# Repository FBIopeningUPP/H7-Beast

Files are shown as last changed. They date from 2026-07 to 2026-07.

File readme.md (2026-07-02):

# H7 Beast

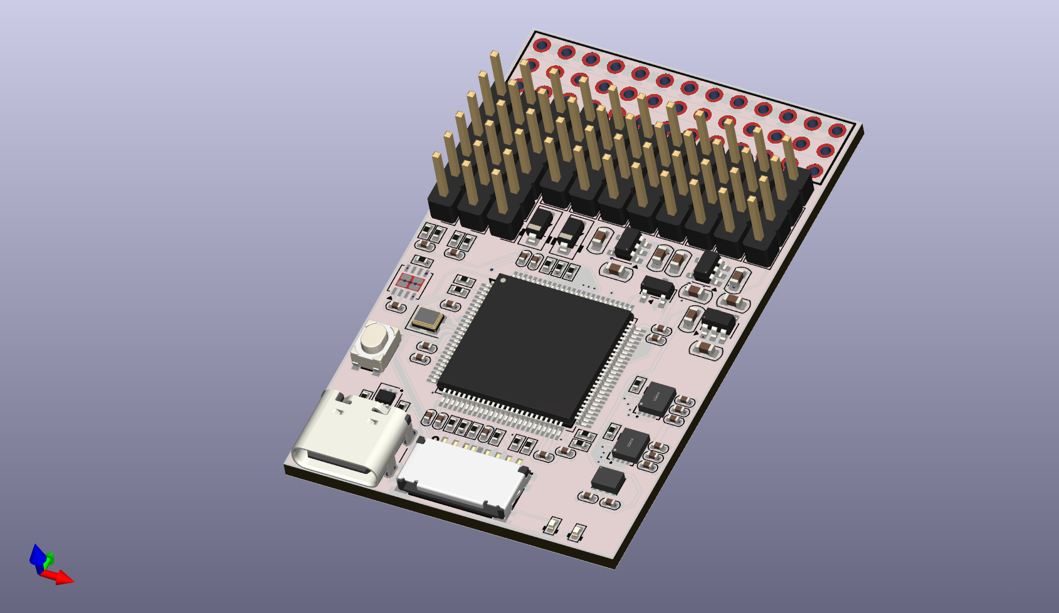
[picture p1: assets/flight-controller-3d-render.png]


H7 Beast is a small open source flight controller that is based of Betaflight, INav, ArduPilot and PX4 firmware. The size of the board with the features is amazing it's just 58x34mm wide and comes with all the features like external spi and canbus and 12 motor output with a single output for ws2812b leds

## Features

- MCU: STM32H743VIT6
- Gyroscope: 2x ICM-42688-P with low noise 3.3v Rail
- Barometer: DPS310
- Blackbox: Sd Card interface
- UARTs: 7x UARTs
- i2C: 2x i2C, 1 internal and 1 external
- SPI: 4x SPI, 3x internal 1x external
- CAN: 1x External Can
- Digital VTX Out: 1x
- MIC5219 low-noise LDO regulators

## Betaflight, INav, ArduPilot and PX4 firmware

As i have used the hardware definition by MatekH743 we can already see the target available in the configurator

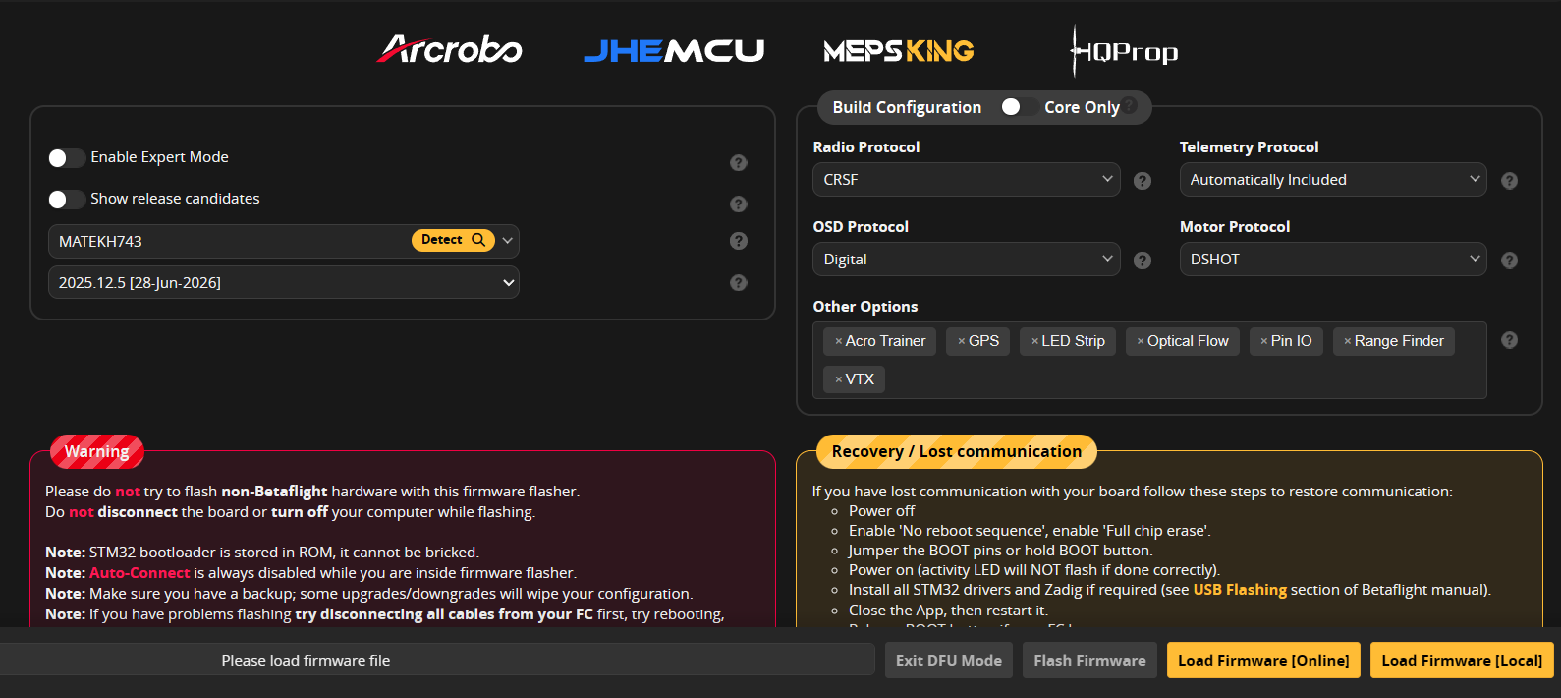
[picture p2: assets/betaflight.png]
betaflight


# PCB Design

This is my first ever 8 layer design for a compact wing based fliht controller, so it is a bit messy but functional

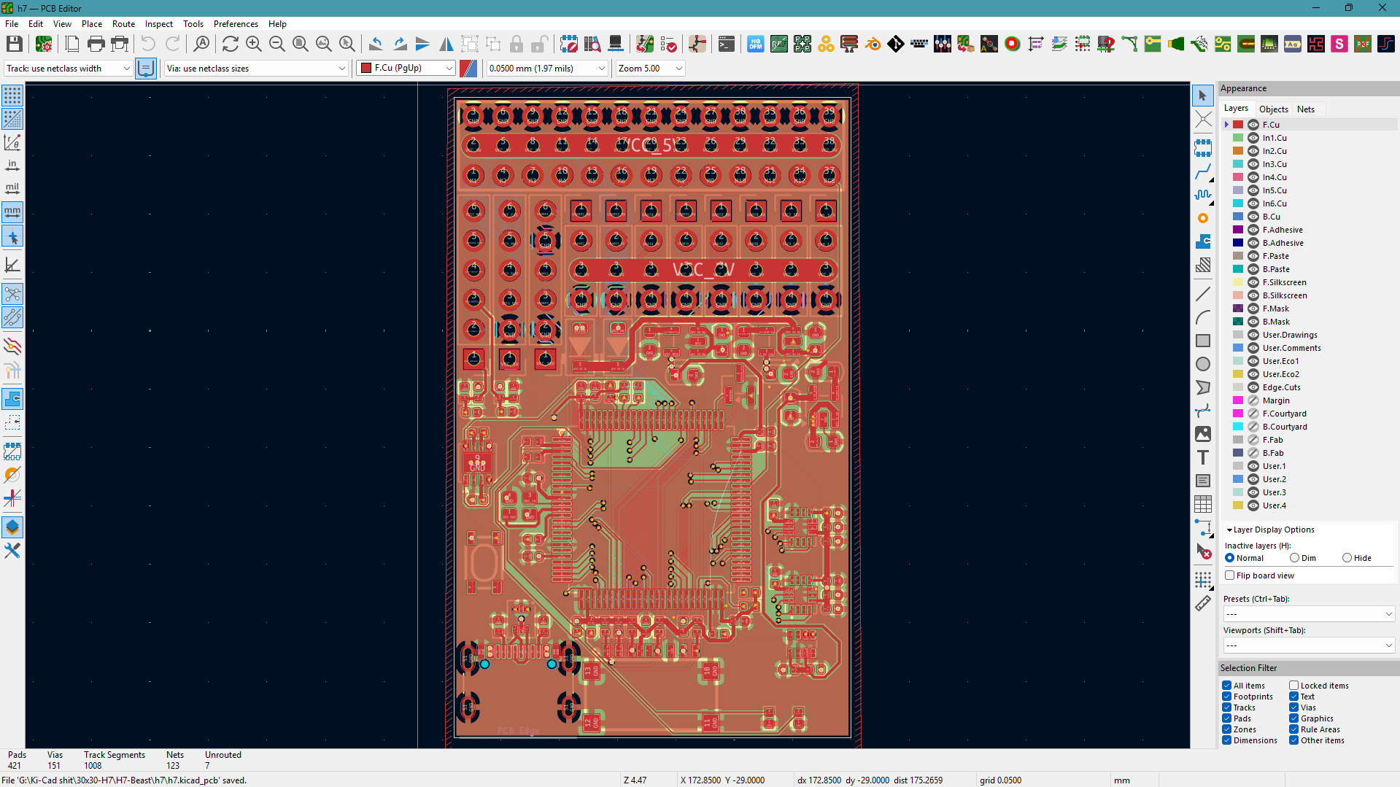
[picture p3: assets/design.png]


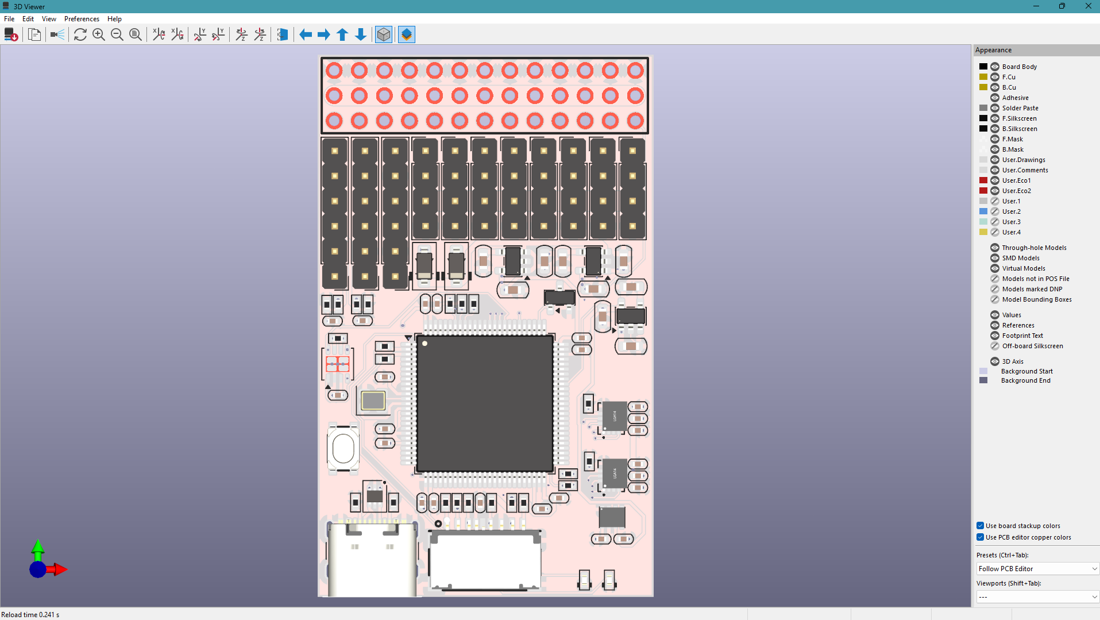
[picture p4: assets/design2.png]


With a Non-BGA chip i have the design pretty easy and managable with 8 layers, and it can fit small uavs easily, it comes with 5v circuit protection from external esc's and 5v from usb input

This can be powered through external 5v bec from the esc's or any other 5v power source

# Steps to reproduce

U can upload the [gerber](production/h7.zip) to the JLCPCB and select 1oz ENIG and 1oz copper for inner layer
For the assembly we only need the front side to be assembled so we can choose that and then upload the [bom](production/bom.csv) and [designator](production/designators.csv) files to get a quote on the bom and u can order the project

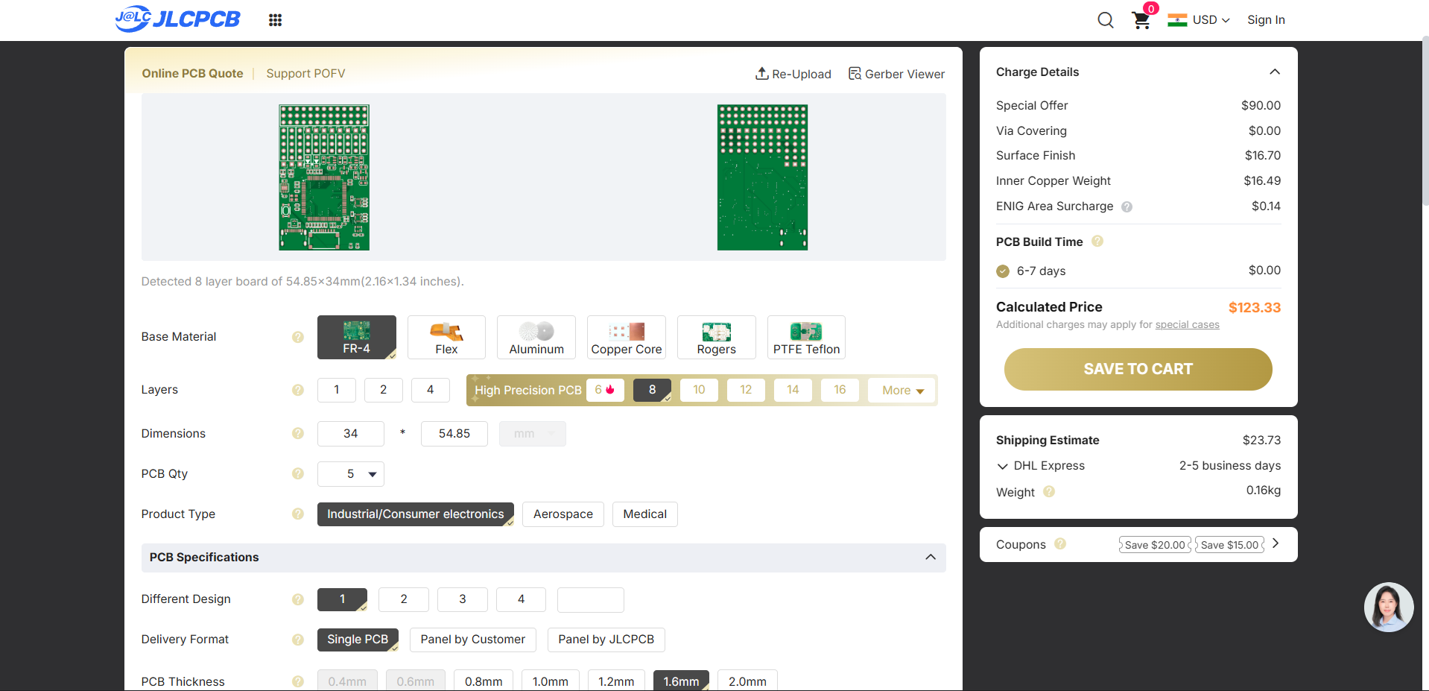
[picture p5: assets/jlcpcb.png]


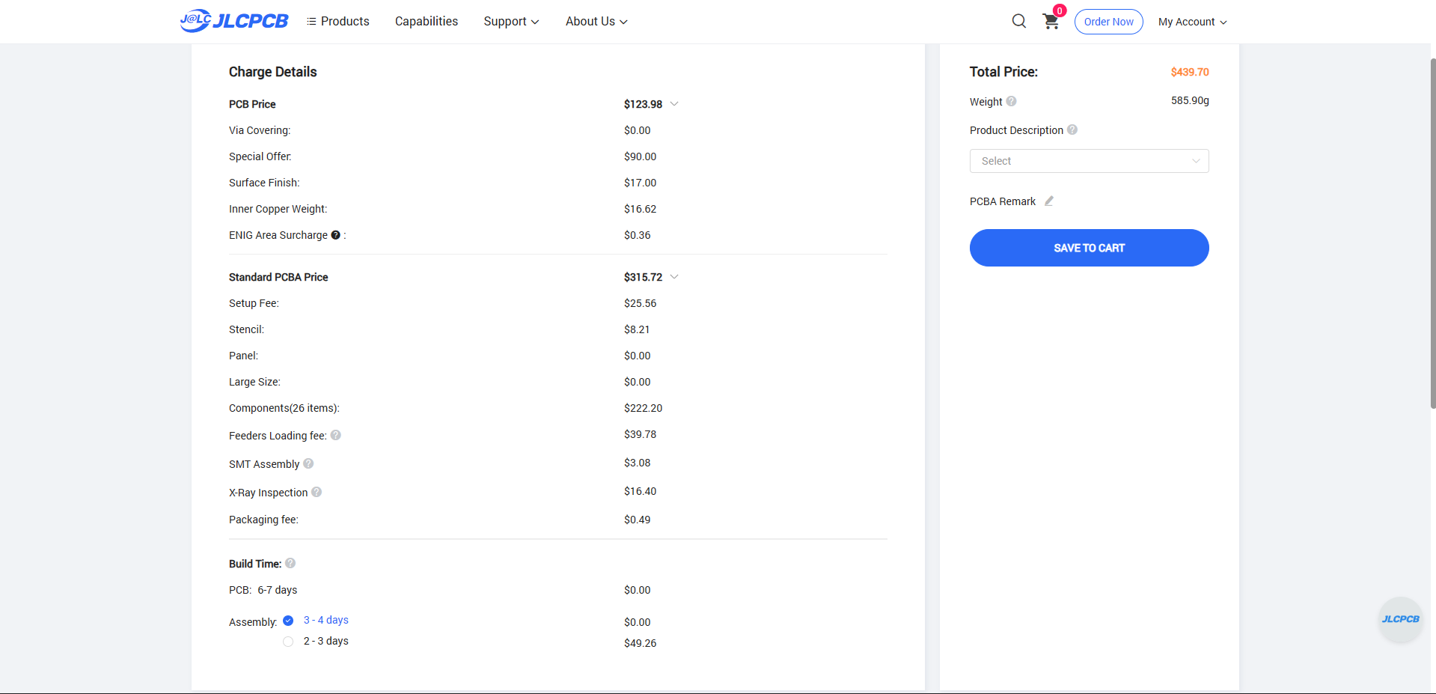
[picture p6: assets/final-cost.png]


But if u want to hand assmeble the whole thing u can also do that by using [Interactive BOM](h7/bom/ibom.html)
It lists all the components and u can select what all part u have sourced and what all parts are needed to be sourced and what u have placed and what not u have placed on the board

### USAGE OF AI

the ai was used to create [pinout](pinout.md) i copied the hwdef from ardupilot github repo and used ai to create a pinout for me so its easier for me to update things in kicad

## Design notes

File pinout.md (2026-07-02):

# H7-Beast Hardware Pinout Reference

This file is a hardware-oriented summary of the board definition in the ChibiOS
pinout format. It is meant to help with KiCad net naming, connector mapping, and
checking board-level routing.

## MCU / Board

- MCU: STM32H743xx
- Board ID: AP_HW_MATEKH743
- Crystal: 8 MHz external oscillator
- Flash size: 2048 KB
- Bootloader reserve: first 128 KB

## USB / Debug

| Function | MCU Pin | Notes |
| --- | --- | --- |
| OTG_FS_DM | PA11 | USB D- |
| OTG_FS_DP | PA12 | USB D+ |
| SWDIO | PA13 | JTAG/SWD |
| SWCLK | PA14 | JTAG/SWD |

## Motor Outputs

| Motor | MCU Pin | Timer / Channel |
| --- | --- | --- |
| M1 | PB0 | TIM8_CH2N |
| M2 | PB1 | TIM8_CH3N |
| M3 | PA0 | TIM5_CH1 |
| M4 | PA1 | TIM5_CH2 |
| M5 | PA2 | TIM5_CH3 |
| M6 | PA3 | TIM5_CH4 |
| M7 | PD12 | TIM4_CH1 |
| M8 | PD13 | TIM4_CH2 |
| M9 | PD14 | TIM4_CH3 |
| M10 | PD15 | TIM4_CH4 |
| M11 | PE5 | TIM15_CH1 |
| M12 | PE6 | TIM15_CH2 |
| M13 / WS2812 | PA8 | TIM1_CH1 |

## UART / Serial

| Port | TX | RX | Notes |
| --- | --- | --- | --- |
| USART1 | PA9 | PA10 | Telem2 |
| USART2 | PD5 | PD6 | GPS1 |
| USART3 | PD8 | PD9 | GPS2 |
| UART4 | PB9 | PB8 | Spare |
| USART6 | PC6 | PC7 | RC input / SERIAL7 |
| UART7 | PE8 | PE7 | Telem1 |
| UART8 | PE1 | PE0 | Spare |

Extra UART control pins:

- UART7 CTS: PE10
- UART7 RTS: PE9
- USART6 alternate RX option: PC7 on ALT(1)

## SPI Buses

| SPI | SCK | MISO | MOSI | Notes |
| --- | --- | --- | --- | --- |
| SPI1 | PA5 | PA6 | PD7 | IMU1 bus |
| SPI2 | PB15 | PB14 | PB13 | OSD bus |
| SPI3 | PB3 | PB4 | PB5 | External bus |
| SPI4 | PE12 | PE13 | PE14 | IMU2 / IMU3 bus |

Chip select / device pins:

- IMU1_CS: PC15
- MAX7456_CS: PB12
- IMU2_CS: PE11
- IMU3_CS: PC13
- EXT_CS1: PD4
- EXT_CS2: PE2
- EXT_CS3: PE15

## IMU / Gyro Devices

| Device | Interface | CS Pin | Notes |
| --- | --- | --- | --- |
| ICM42688 | SPI1 | PC15 | Primary IMU option |
| MPU6000 | SPI1 | PC15 | Alternate IMU option |
| ICM20602 | SPI4 | PE11 | Alternate IMU option |
| ICM42605 | SPI4 | PC13 | Backup IMU option |

## I2C Buses

| I2C | SCL | SDA |
| --- | --- | --- |
| I2C1 | PB6 | PB7 |
| I2C2 | PB10 | PB11 |

## CAN

| Function | MCU Pin | Notes |
| --- | --- | --- |
| CAN1_RX | PD0 | CAN bus RX |
| CAN1_TX | PD1 | CAN bus TX |
| CAN1_SILENT | PD3 | Silent mode control |

## Analog / ADC

| Function | MCU Pin | ADC | Notes |
| --- | --- | --- | --- |
| BATT_VOLTAGE_SENS | PC0 | ADC1 | Battery 1 voltage |
| BATT_CURRENT_SENS | PC1 | ADC1 | Battery 1 current |
| BATT2_VOLTAGE_SENS | PA4 | ADC1 | Battery 2 voltage |
| BATT2_CURRENT_SENS | PA7 | ADC1 | Battery 2 current |
| PRESSURE_SENS | PC4 | ADC1 | Airspeed / pressure |
| RSSI_ADC | PC5 | ADC1 | Analog RSSI |

Defined analog mapping values:

- HAL_BATT_MONITOR_DEFAULT: 4
- HAL_BATT_VOLT_PIN: 10
- HAL_BATT_CURR_PIN: 11
- HAL_BATT2_VOLT_PIN: 18
- HAL_BATT2_CURR_PIN: 7
- HAL_BATT_VOLT_SCALE: 11.0
- HAL_BATT_CURR_SCALE: 40.0
- HAL_BATT2_VOLT_SCALE: 11.0
- HAL_DEFAULT_AIRSPEED_PIN: 4
- BOARD_RSSI_ANA_PIN: 8

## LEDs / Beeper

| Function | MCU Pin | Notes |
| --- | --- | --- |
| LED0 | PE3 | Blue |
| LED1 | PE4 | Green |
| Beeper / ALARM | PA15 | TIM2_CH1 |

GPIO LED assignments:

- HAL_GPIO_A_LED_PIN: 91
- HAL_GPIO_B_LED_PIN: 90
- AP_NOTIFY_GPIO_LED_2_ENABLED: 1

## Storage / SD Card

| Function | MCU Pin |
| --- | --- |
| SDMMC1_D0 | PC8 |
| SDMMC1_D1 | PC9 |
| SDMMC1_D2 | PC10 |
| SDMMC1_D3 | PC11 |
| SDMMC1_CK | PC12 |
| SDMMC1_CMD | PD2 |

Flash storage settings:

- HAL_STORAGE_SIZE: 32768
- STORAGE_FLASH_PAGE: 14

## GPIO / User IO

| Function | MCU Pin | Notes |
| --- | --- | --- |
| PINIO1 | PD10 | Output, LOW default |
| PINIO2 | PD11 | Output, LOW default |

## External / Expansion Notes

- External compass probing is enabled; no built-in compass is defined.
- SPI3 is intended for external peripherals such as PixartFlow on EXT_CS1.
- DMA is configured with `DMA_PRIORITY S*` and `DMA_NOSHARE SPI1* SPI4*` in the board definition.

## Useful KiCad Net Names

When naming connectors or footprints in KiCad, these are the most useful nets to keep aligned with the board definition:

- USB: PA11, PA12
- SWD: PA13, PA14
- IMU1 SPI: PA5, PA6, PD7, PC15
- IMU2 / IMU3 SPI: PE12, PE13, PE14, PE11, PC13
- OSD SPI: PB15, PB14, PB13, PB12
- External SPI3: PB3, PB4, PB5, PD4, PE2, PE15
- UARTs: PA9/PA10, PD5/PD6, PD8/PD9, PB9/PB8, PC6/PC7, PE8/PE7, PE1/PE0
- I2C: PB6/PB7, PB10/PB11
- CAN: PD0/PD1/PD3
- ADC: PC0, PC1, PA4, PA7, PC4, PC5

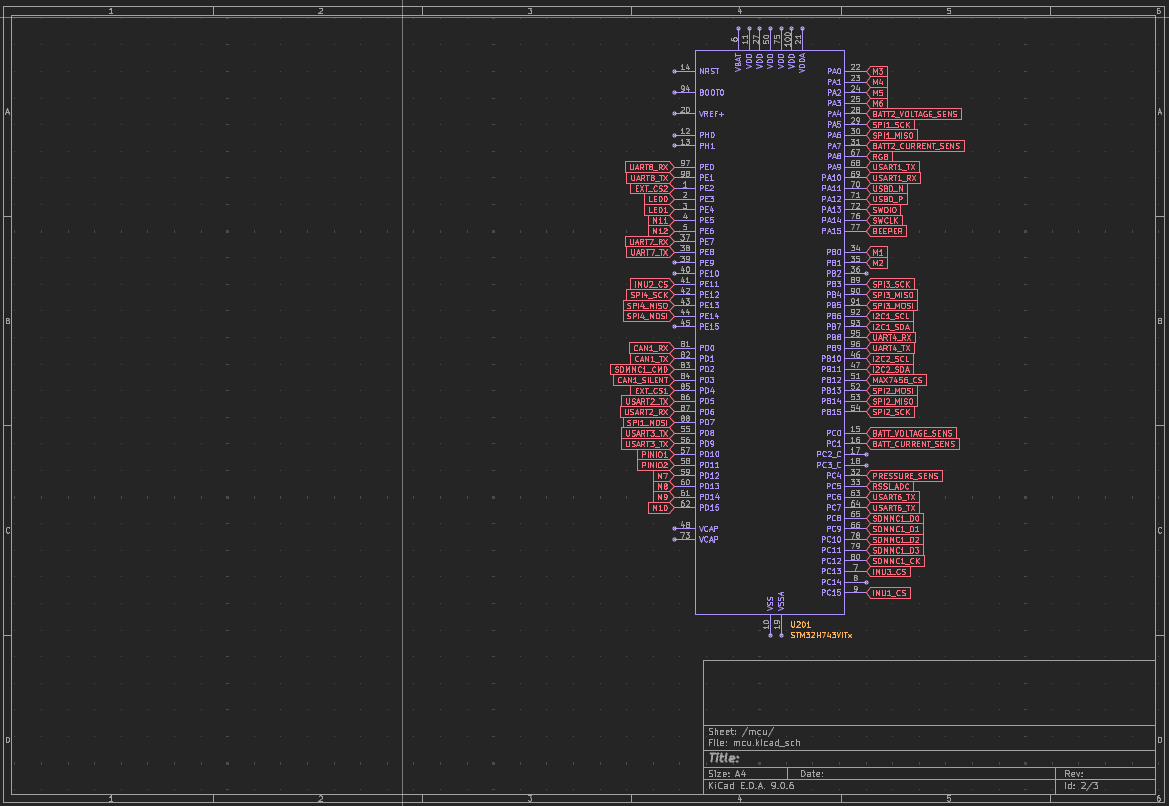
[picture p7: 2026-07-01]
images/image.png

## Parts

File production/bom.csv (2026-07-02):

Designator | Footprint | Quantity | Value | LCSC Part #
C201, C202, C203, C204, C205, C207, C210, C307, C308, C401, C402, C501, C503 | 0402 | 13 | 100nF
C206, C502 | 0402 | 2 | 1uF
C208, C209 | 0402 | 2 | 4.7uF
C301, C306 | 0402 | 2 | 10nF
C302, C304 | 0402 | 2 | 0.1uF
C303, C305 | 0402 | 2 | 2.2uF
C403, C404, C405 | 0603 | 3 | 2.2uF
C406, C407, C408 | 0603 | 3 | 470pF
C409, C410, C411 | 0603 | 3 | 100nF
D402, D403 | D_SOD-123 | 2 | B140HW-7
D501 | SOT-666 | 1 | USBLC6-2P6
J301 | PinHeader_1x06_P2.54mm_Vertical | 1 | VTX&UART1
J501 | USB_C_Receptacle_GCT_USB4105-xx-A_16P_TopMnt_Horizontal | 1 | USBC
J505 | PinHeader_1x04_P2.54mm_Vertical | 1 | UART2
J506 | PinHeader_1x04_P2.54mm_Vertical | 1 | USART3
J508 | PinHeader_1x04_P2.54mm_Vertical | 1 | UART4
J509 | PinHeader_1x04_P2.54mm_Vertical | 1 | USART6
J510 | PinHeader_1x04_P2.54mm_Vertical | 1 | UART7
J511 | PinHeader_1x04_P2.54mm_Vertical | 1 | UART8
J512 | PinHeader_1x06_P2.54mm_Vertical | 1 | SPI3
J513 | PinHeader_1x04_P2.54mm_Vertical | 1 | I2C2
J514 | PinHeader_1x04_P2.54mm_Vertical | 1 | CAN
J515 | PinHeader_1x06_P2.54mm_Vertical | 1 | EXT SENS
LED201, LED202 | 0402 | 2 | LED_0402
Q501 | SOT-23 | 1 | SS8050
R201, R202, R203, R204 | 0402 | 4 | 4.7k
R205, R301, R302, R503, R504, R505, R506, R507, R508 | 0402 | 9 | 10k
R206, R207 | 0402 | 2 | 100
R401, R402, R403, R404 | 0402 | 4 | 1k
R501, R502 | 0402 | 2 | 5.1k
R509 | 0402 | 1 | 120
SW201 | KEY-SMD_4P-L4.2-W3.2-P2.20-LS4.6 | 1 | SKRPABE010 | C115360
U201 | LQFP-100_14x14mm_P0.5mm | 1 | STM32H743VITx
U301, U302 | LGA-14_L3.0-W2.5-P0.50-TL | 2 | ICM-42688-P | C1850418
U303 | LGA-8_DPS310XTSA1 | 1 | DPS310XTSA1 | C130156
U401, U402, U403 | SOT-23-5 | 3 | MIC5219-3.3YM5
U501 | TF-SMD_TF-123-ARP9H15 | 1 | TF-123-ARP9H17 | C2982548
U502 | HVSON-8-1EP_3x3mm_P0.65mm_EP1.6x2.4mm | 1 | TJA1051TK-3
U503 | HDR-TH_39P-P2.54-V-M-R3-C13-S2.54 | 1 | KH-2.54PH180-3X13P-L11.5 | C20610260
Y201 | Crystal_SMD_2520-4Pin_2.5x2.0mm | 1 | 8mhz

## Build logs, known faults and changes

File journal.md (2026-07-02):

---
title: "H7-Beast"
author: "Milind Singh"
description: "H743 Flight Controller"
created_at: "2026-07-02"
---

#July 2nd:
Today i started building the project, i took the matekh743 pinout as refrence for the design and created a pinout.md to help me further create the kicad schematic

in the kicad project i added my main components like stm32h743 icm gyro and dsp barometer

i added the power regulators, diodes and connectors to the kicad schematic and also binded the capacitors that are required for noise reducation amd emf reduction

i updated everything to the design 

in the design i first started with 6 layers but figured out for a  noob like me it is not enough than i shifted to 8 layers for better sepration of power place on bottom layer so the gyro can live happily 

i finished the design by routing all the layers with the help of the schematic and the kicad

while making the design i updated the drc to suit my whole project like the track size and the via size and all the copper clearance and the clearance for the 

and then i finished the project with final drc checks and everything and it is good to go

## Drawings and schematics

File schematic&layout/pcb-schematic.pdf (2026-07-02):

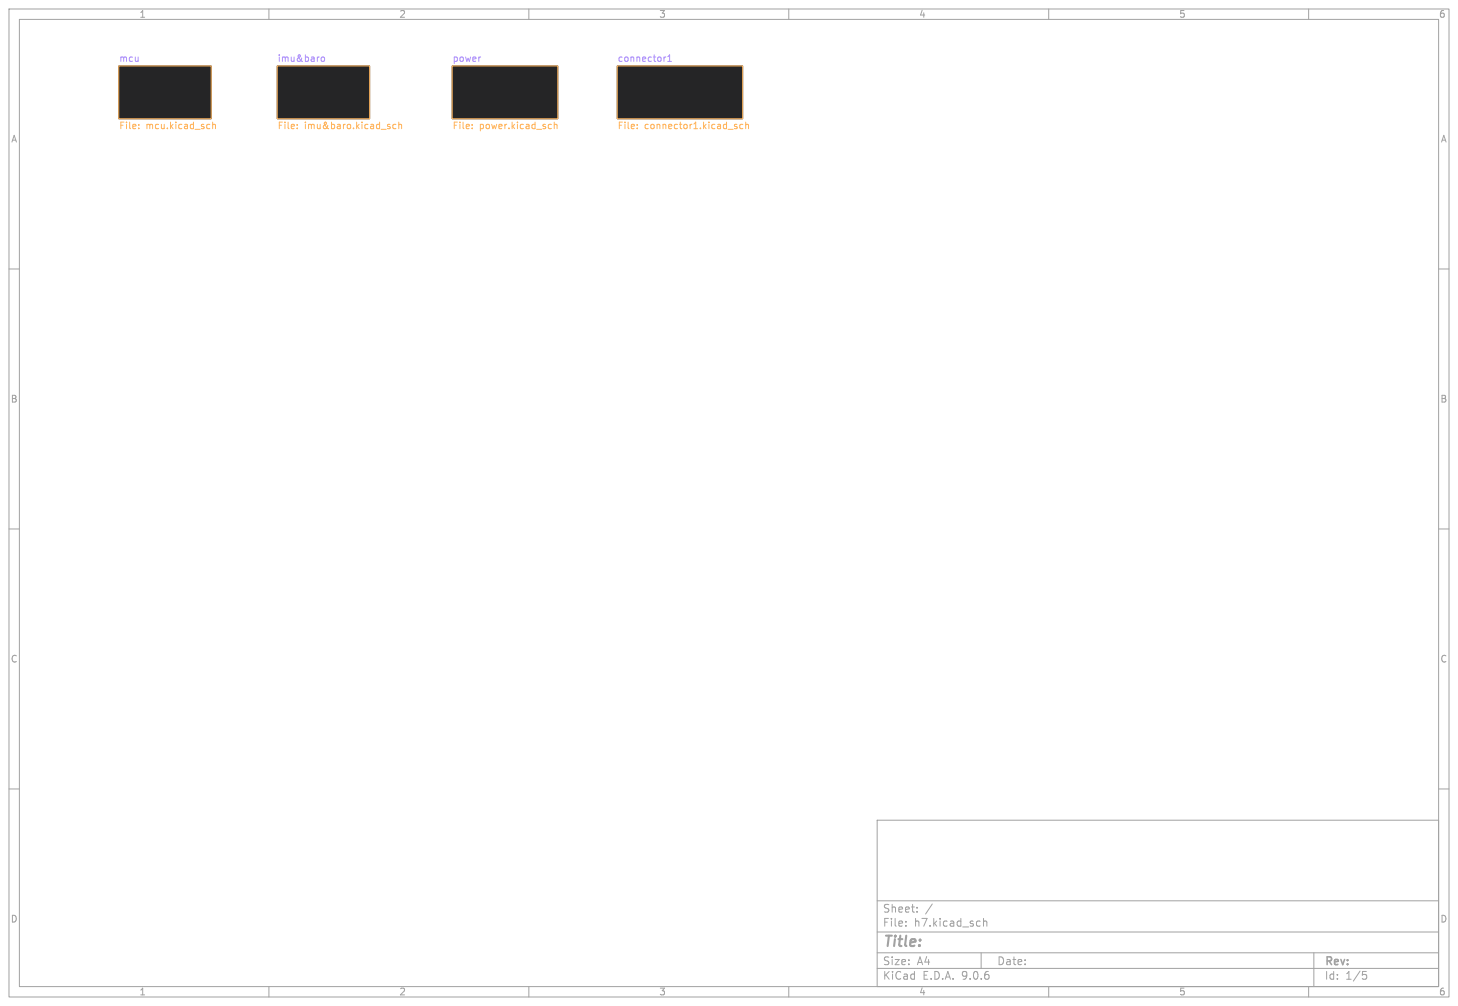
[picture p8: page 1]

power File: power.kicad_sch mcu File: mcu.kicad_sch

imu&baro File: imu&baro.kicad_sch

Id: 1/5 Title: File: h7.kicad_sch Sheet: /

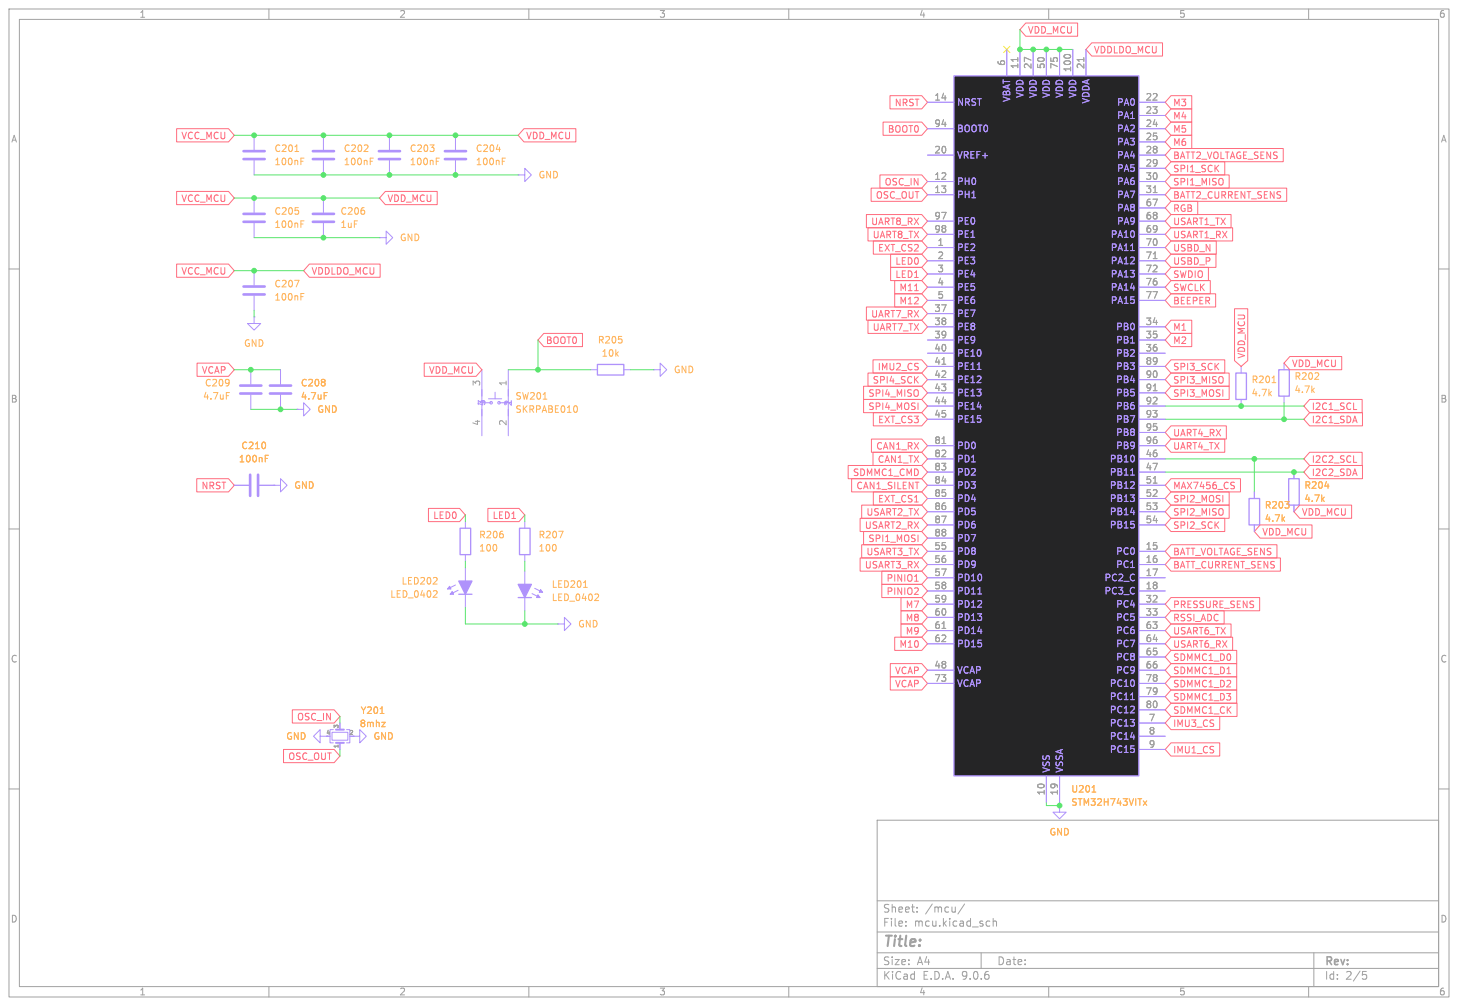
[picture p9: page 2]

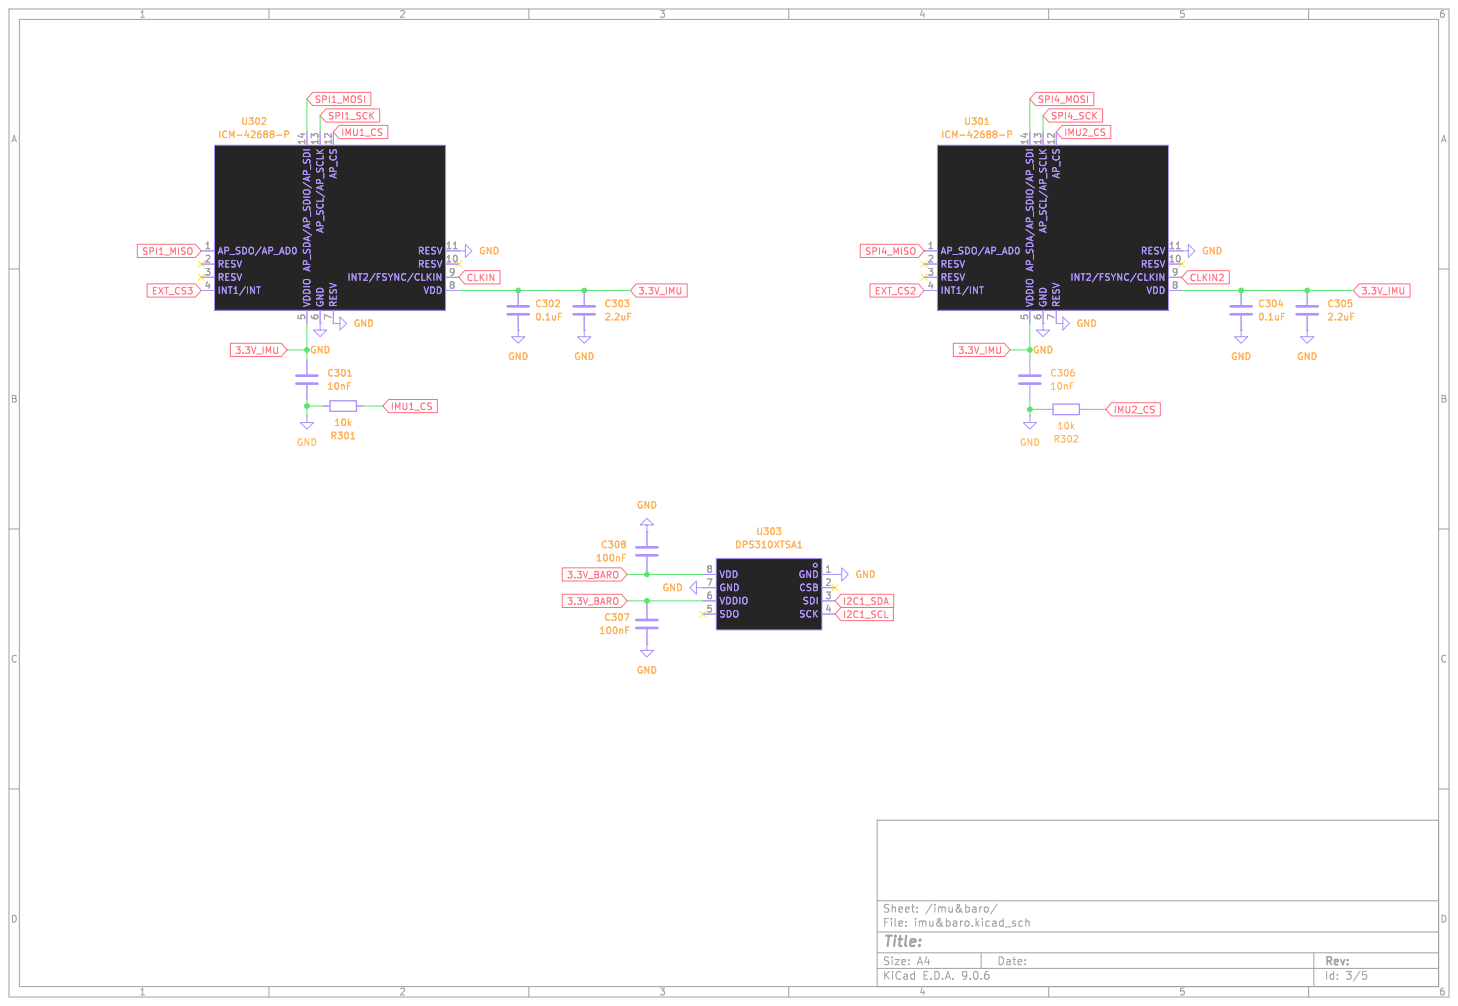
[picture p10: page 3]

Id: 3/5 Title: File: imu&baro.kicad_sch Sheet: /imu&baro/

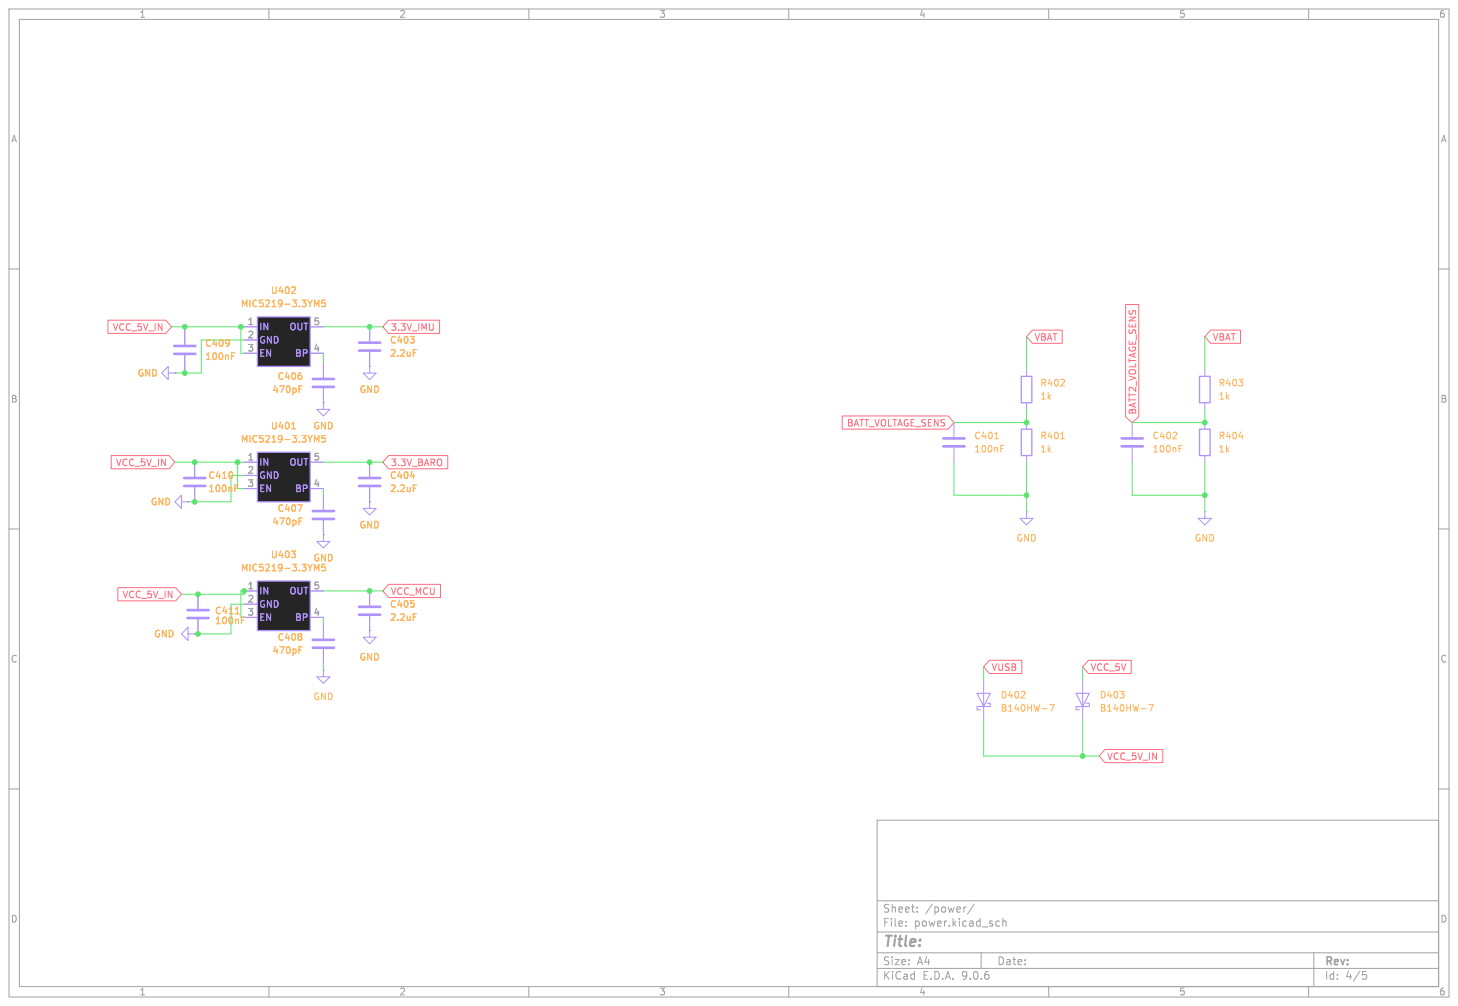
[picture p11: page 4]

Id: 4/5 Title: File: power.kicad_sch Sheet: /power/ GND

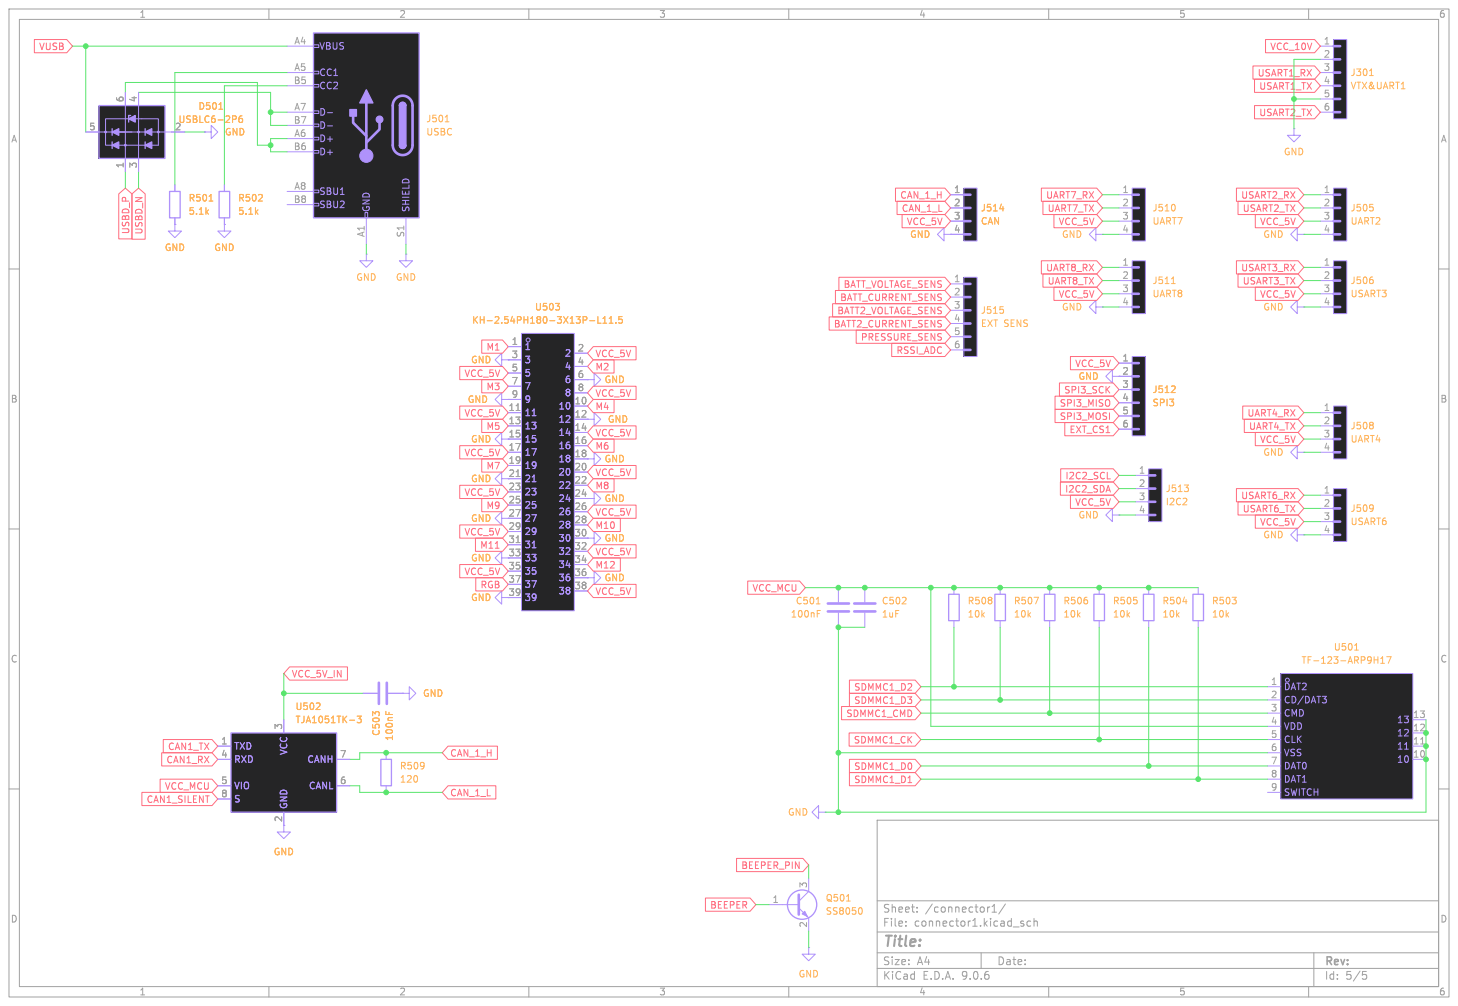
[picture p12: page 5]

Id: 5/5 Title: File: connector1.kicad_sch Sheet: /connector1/

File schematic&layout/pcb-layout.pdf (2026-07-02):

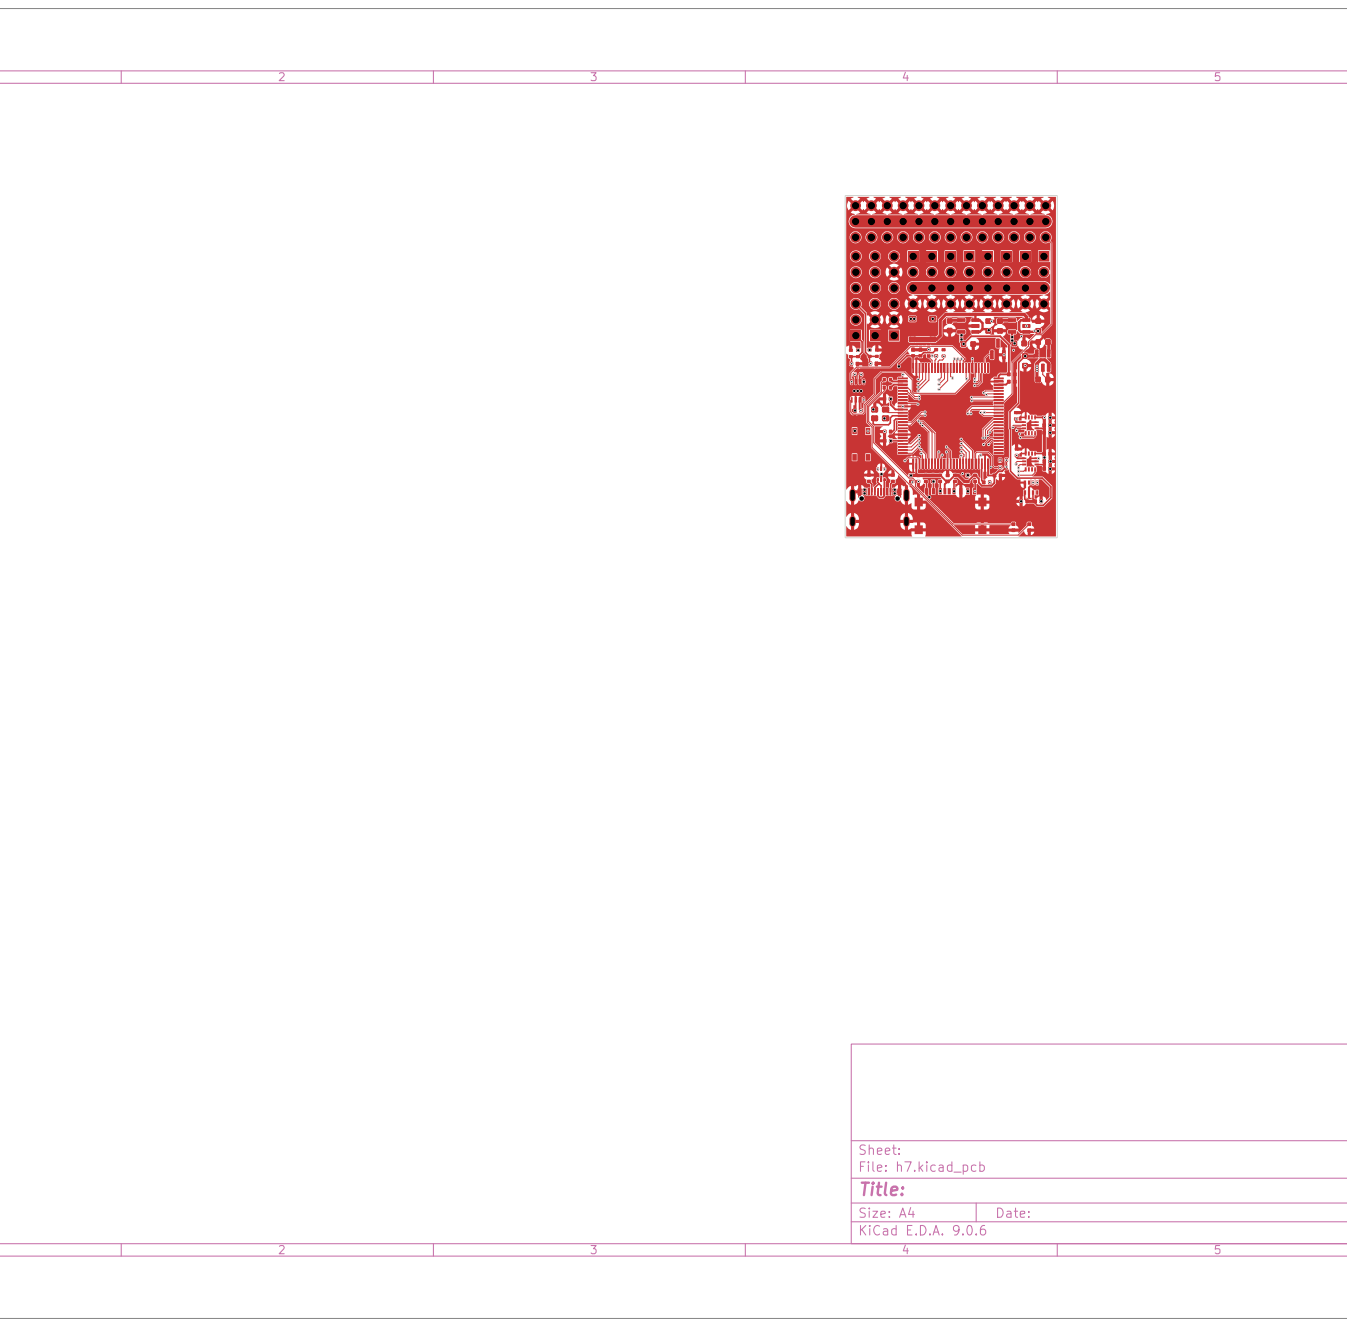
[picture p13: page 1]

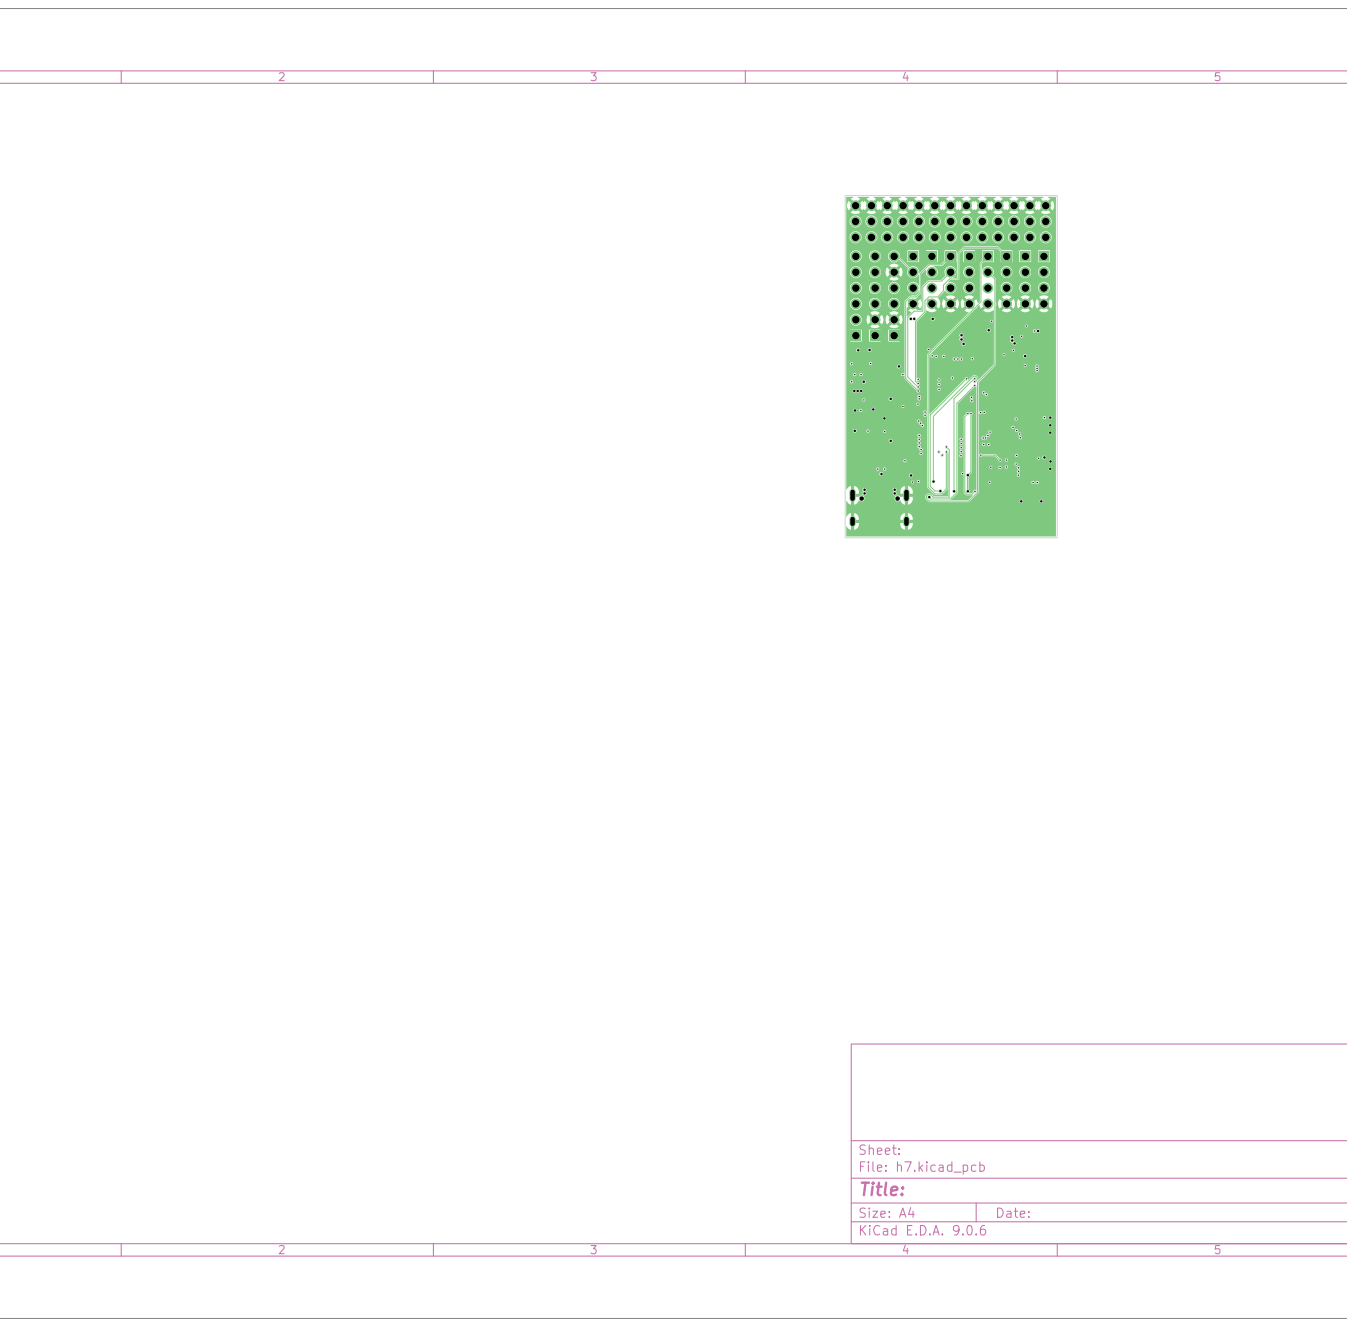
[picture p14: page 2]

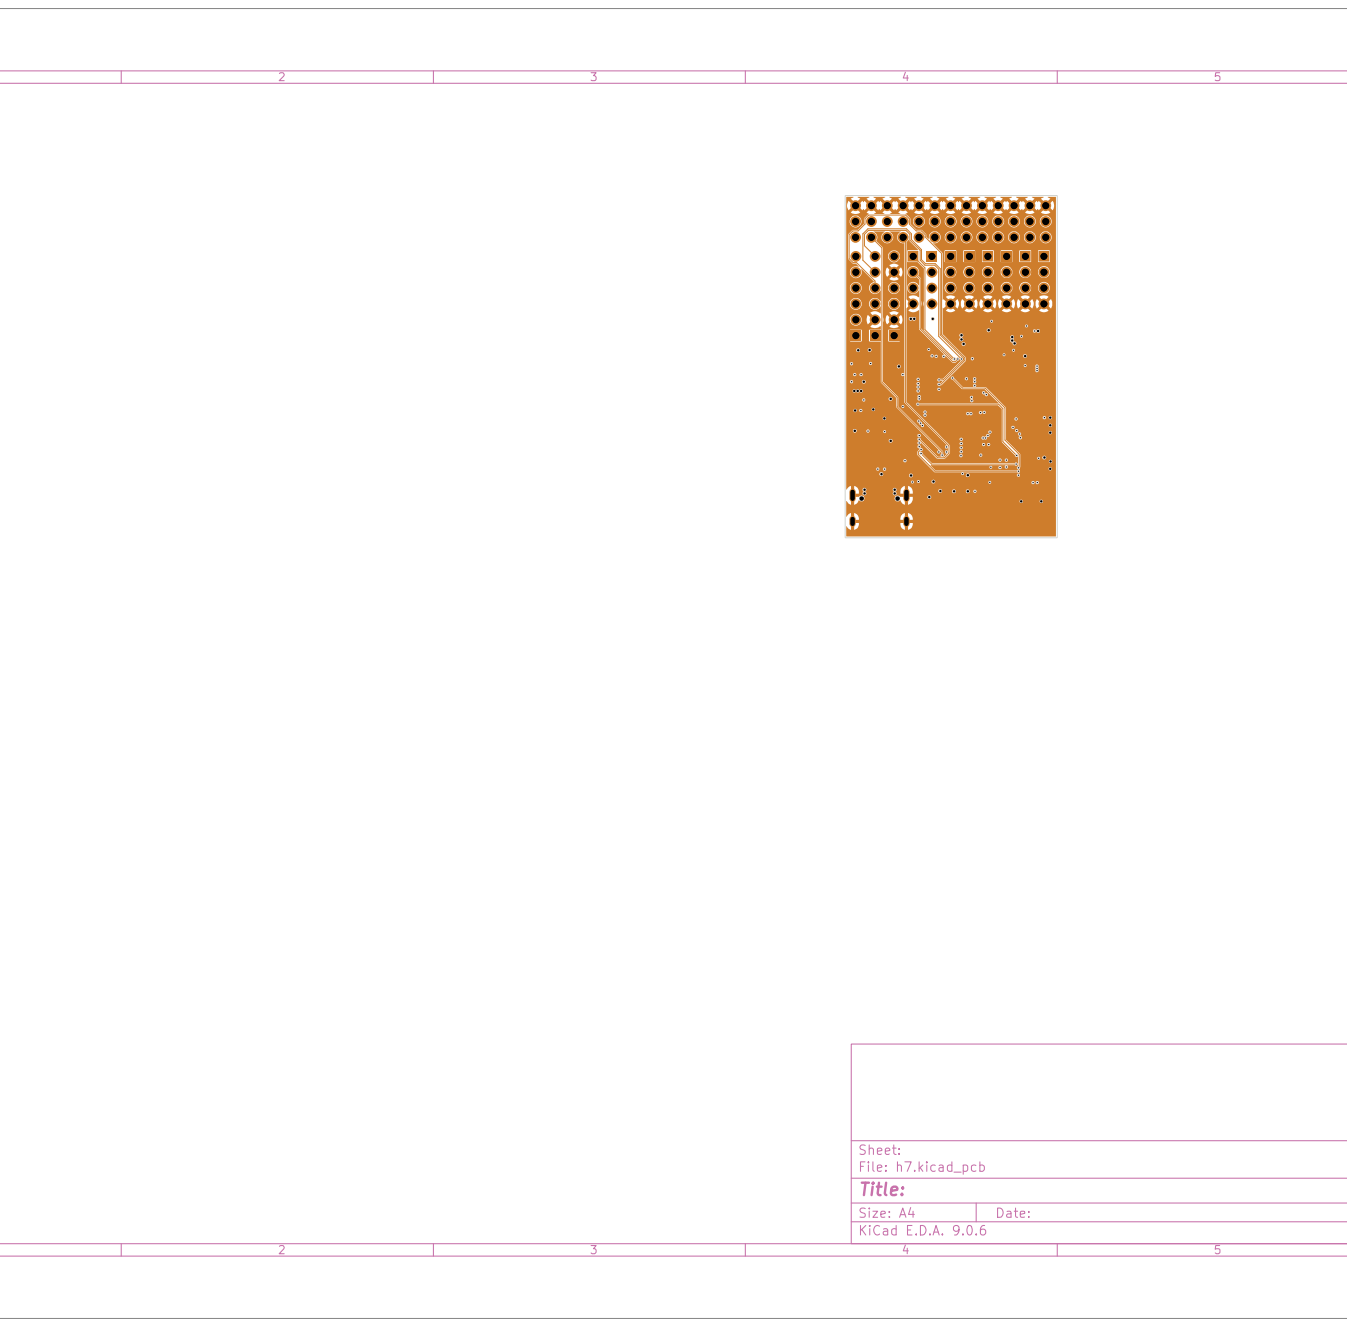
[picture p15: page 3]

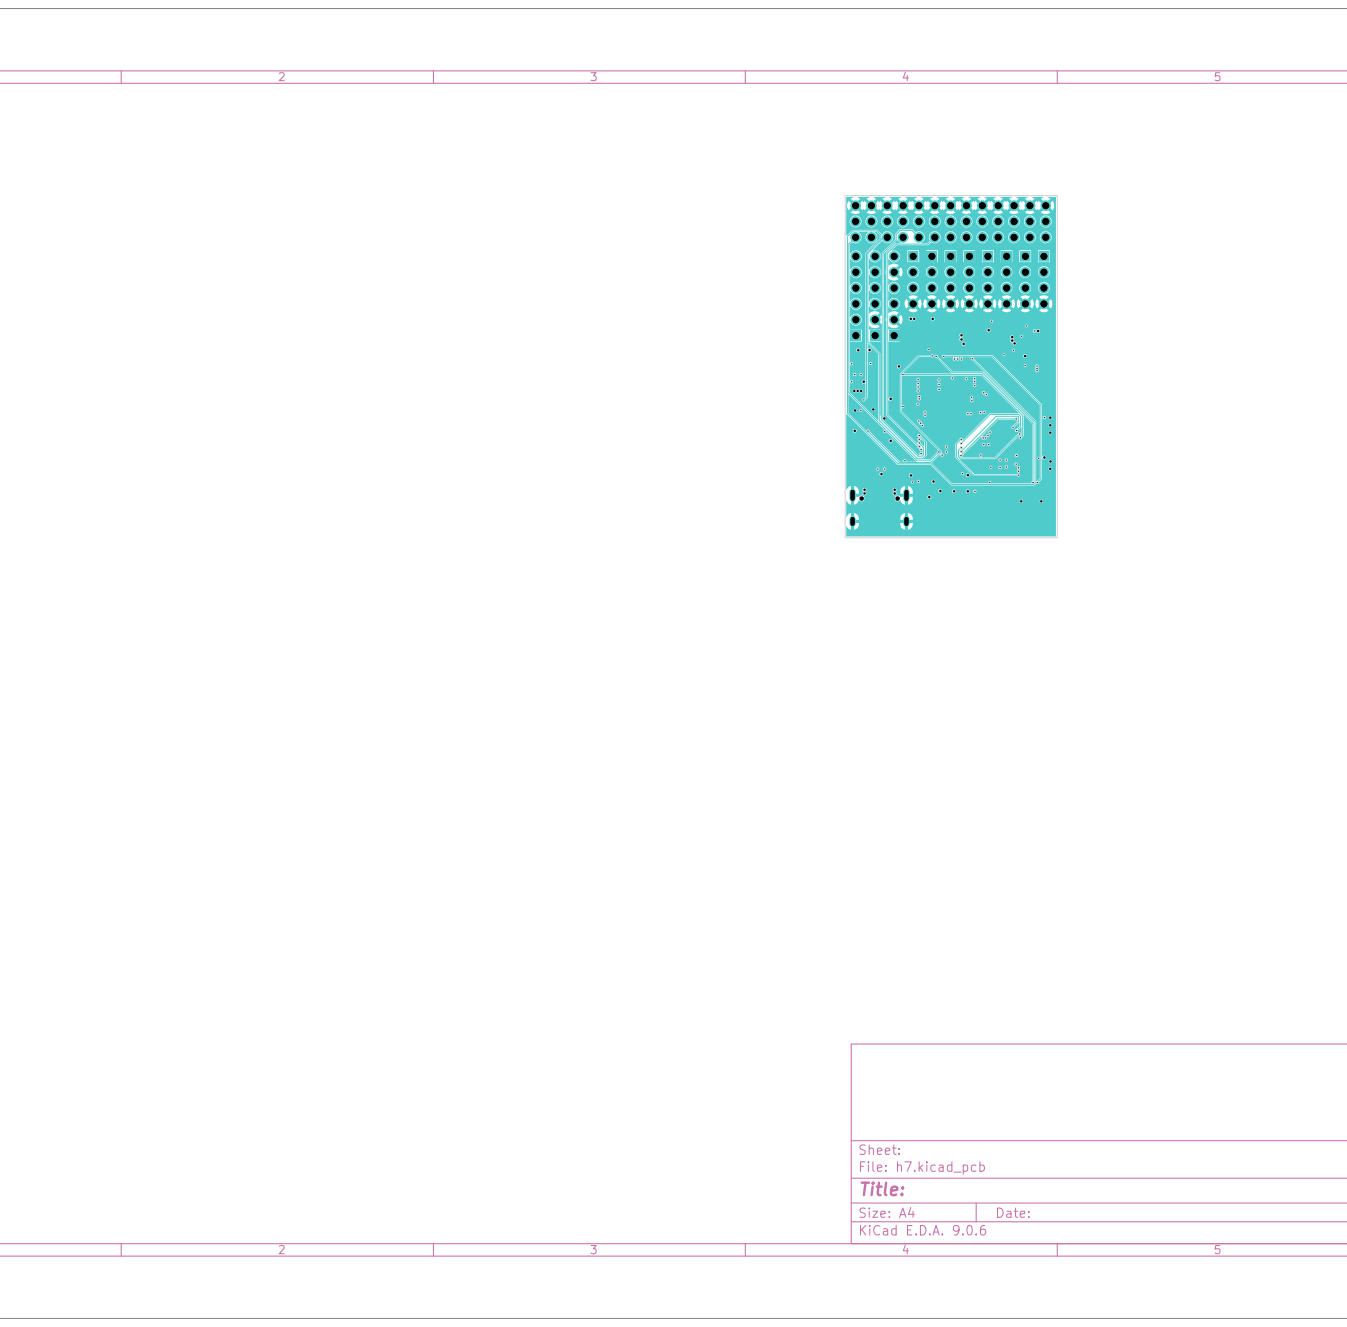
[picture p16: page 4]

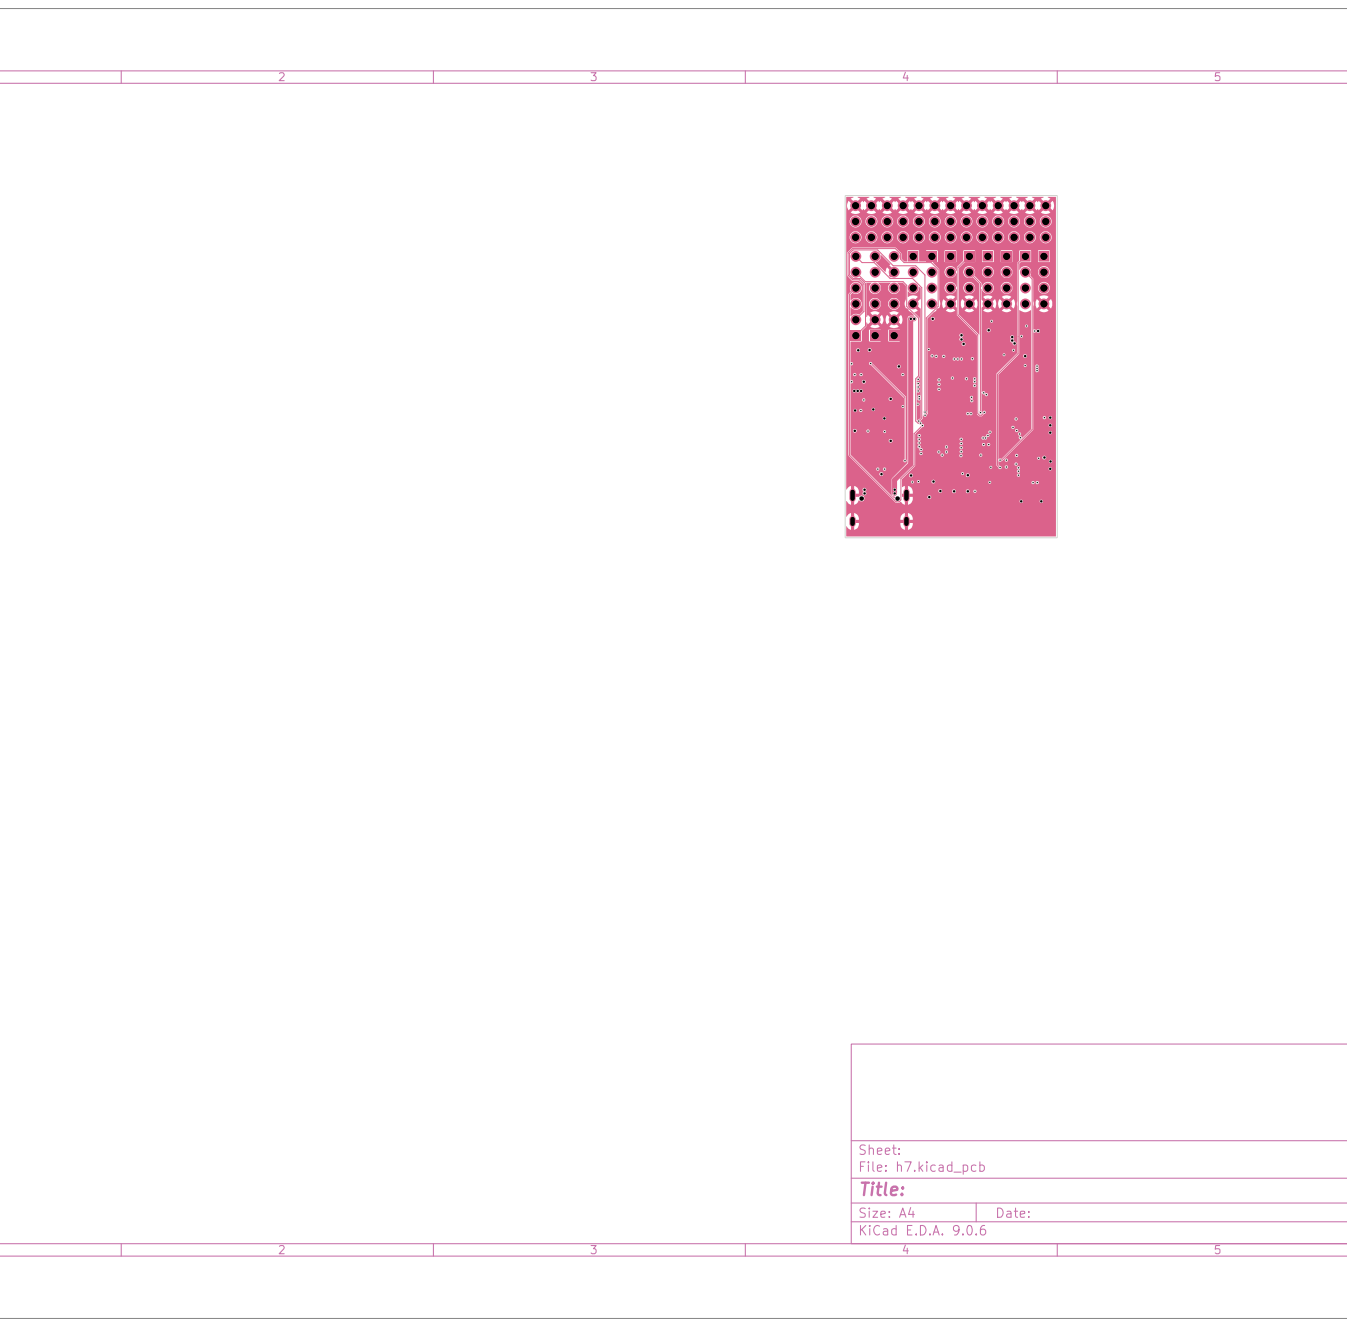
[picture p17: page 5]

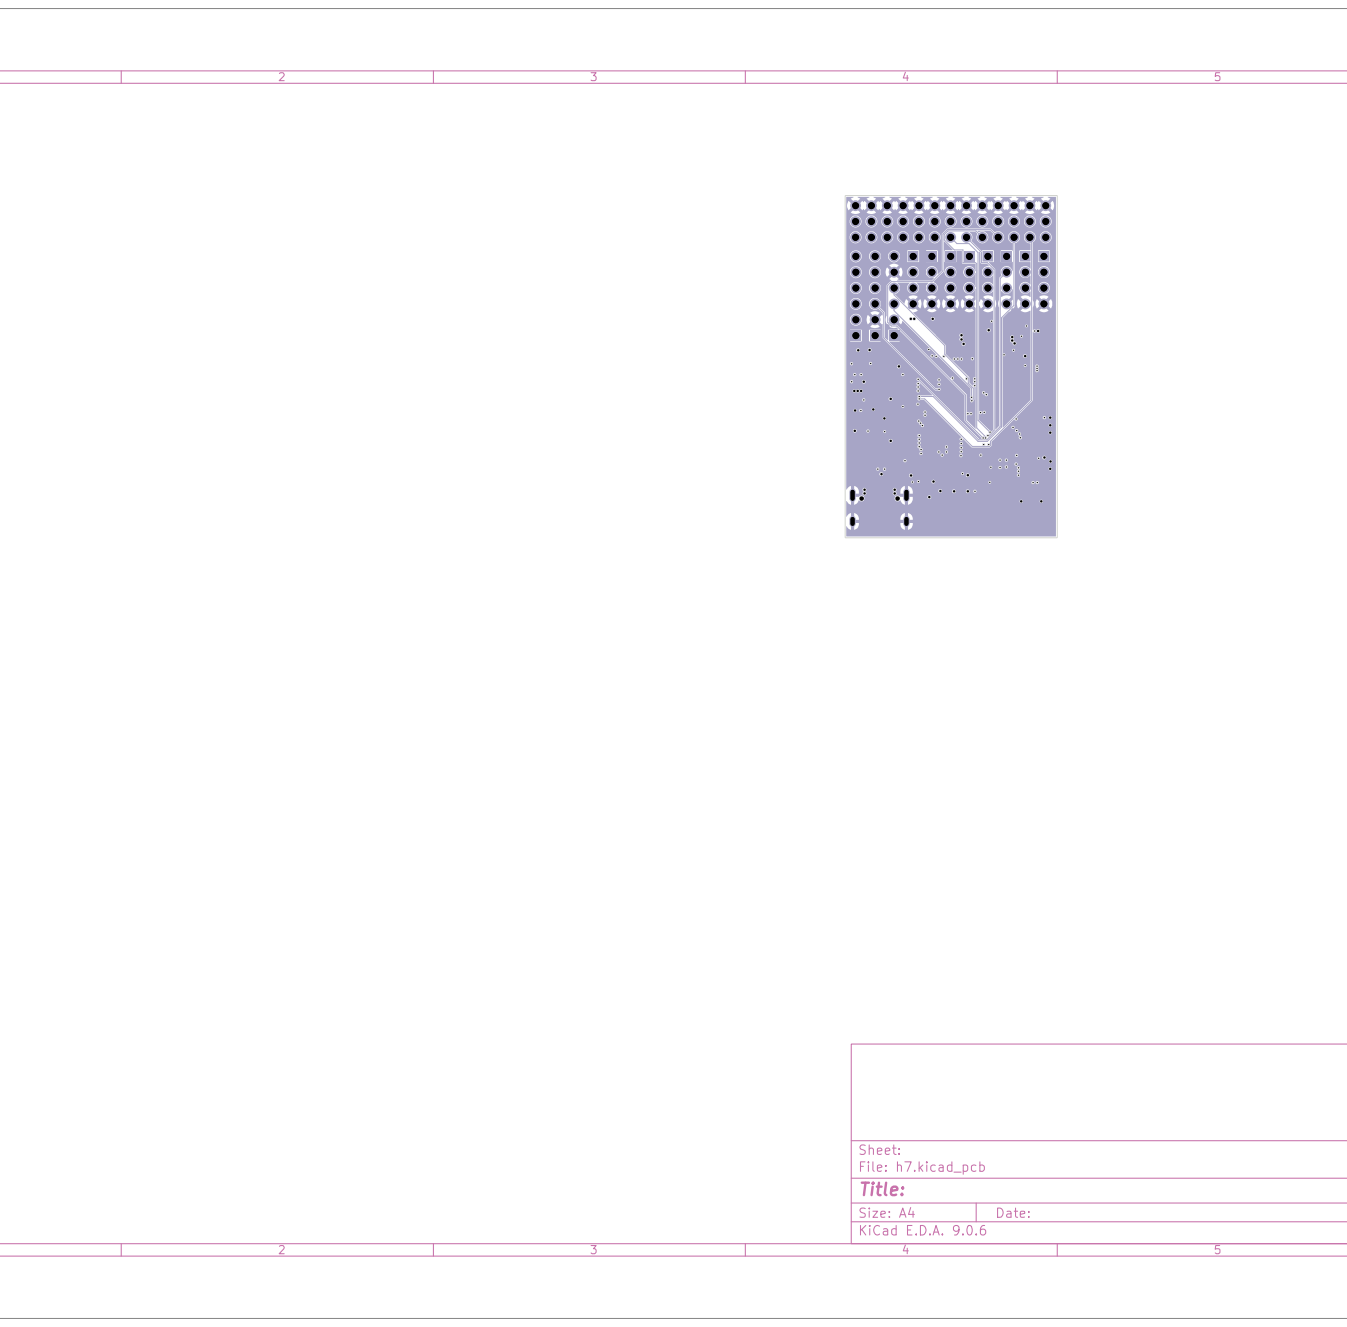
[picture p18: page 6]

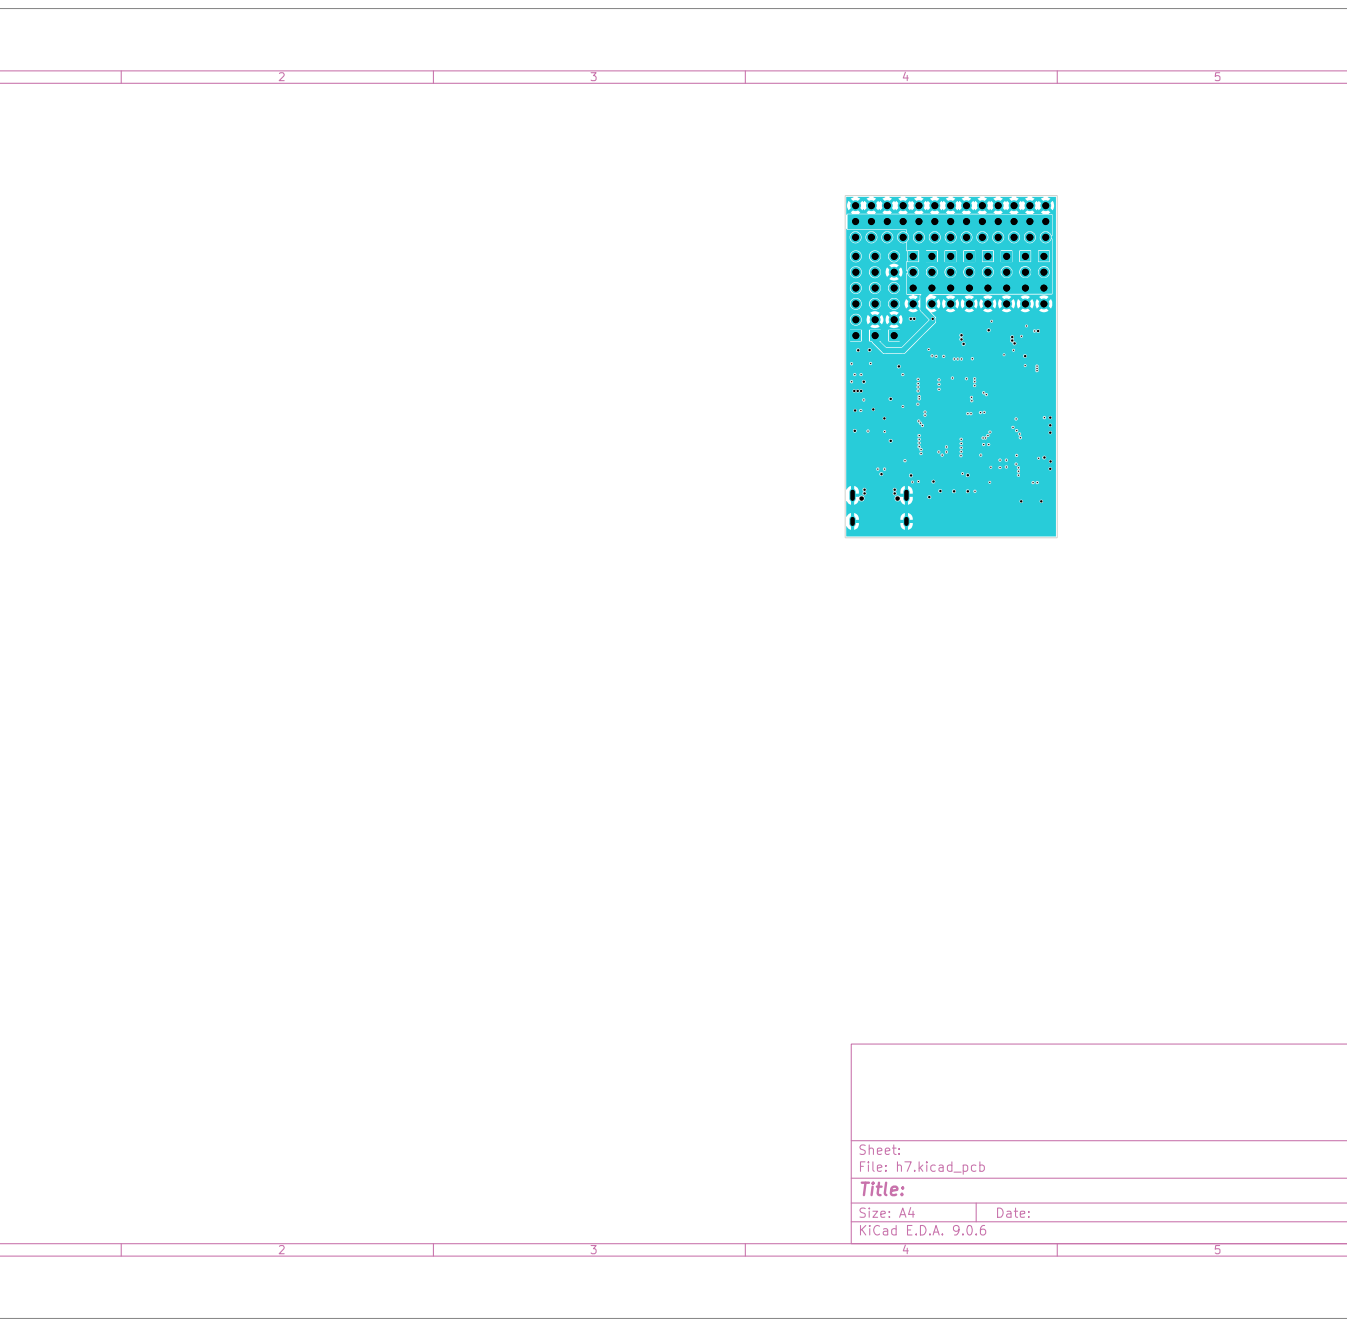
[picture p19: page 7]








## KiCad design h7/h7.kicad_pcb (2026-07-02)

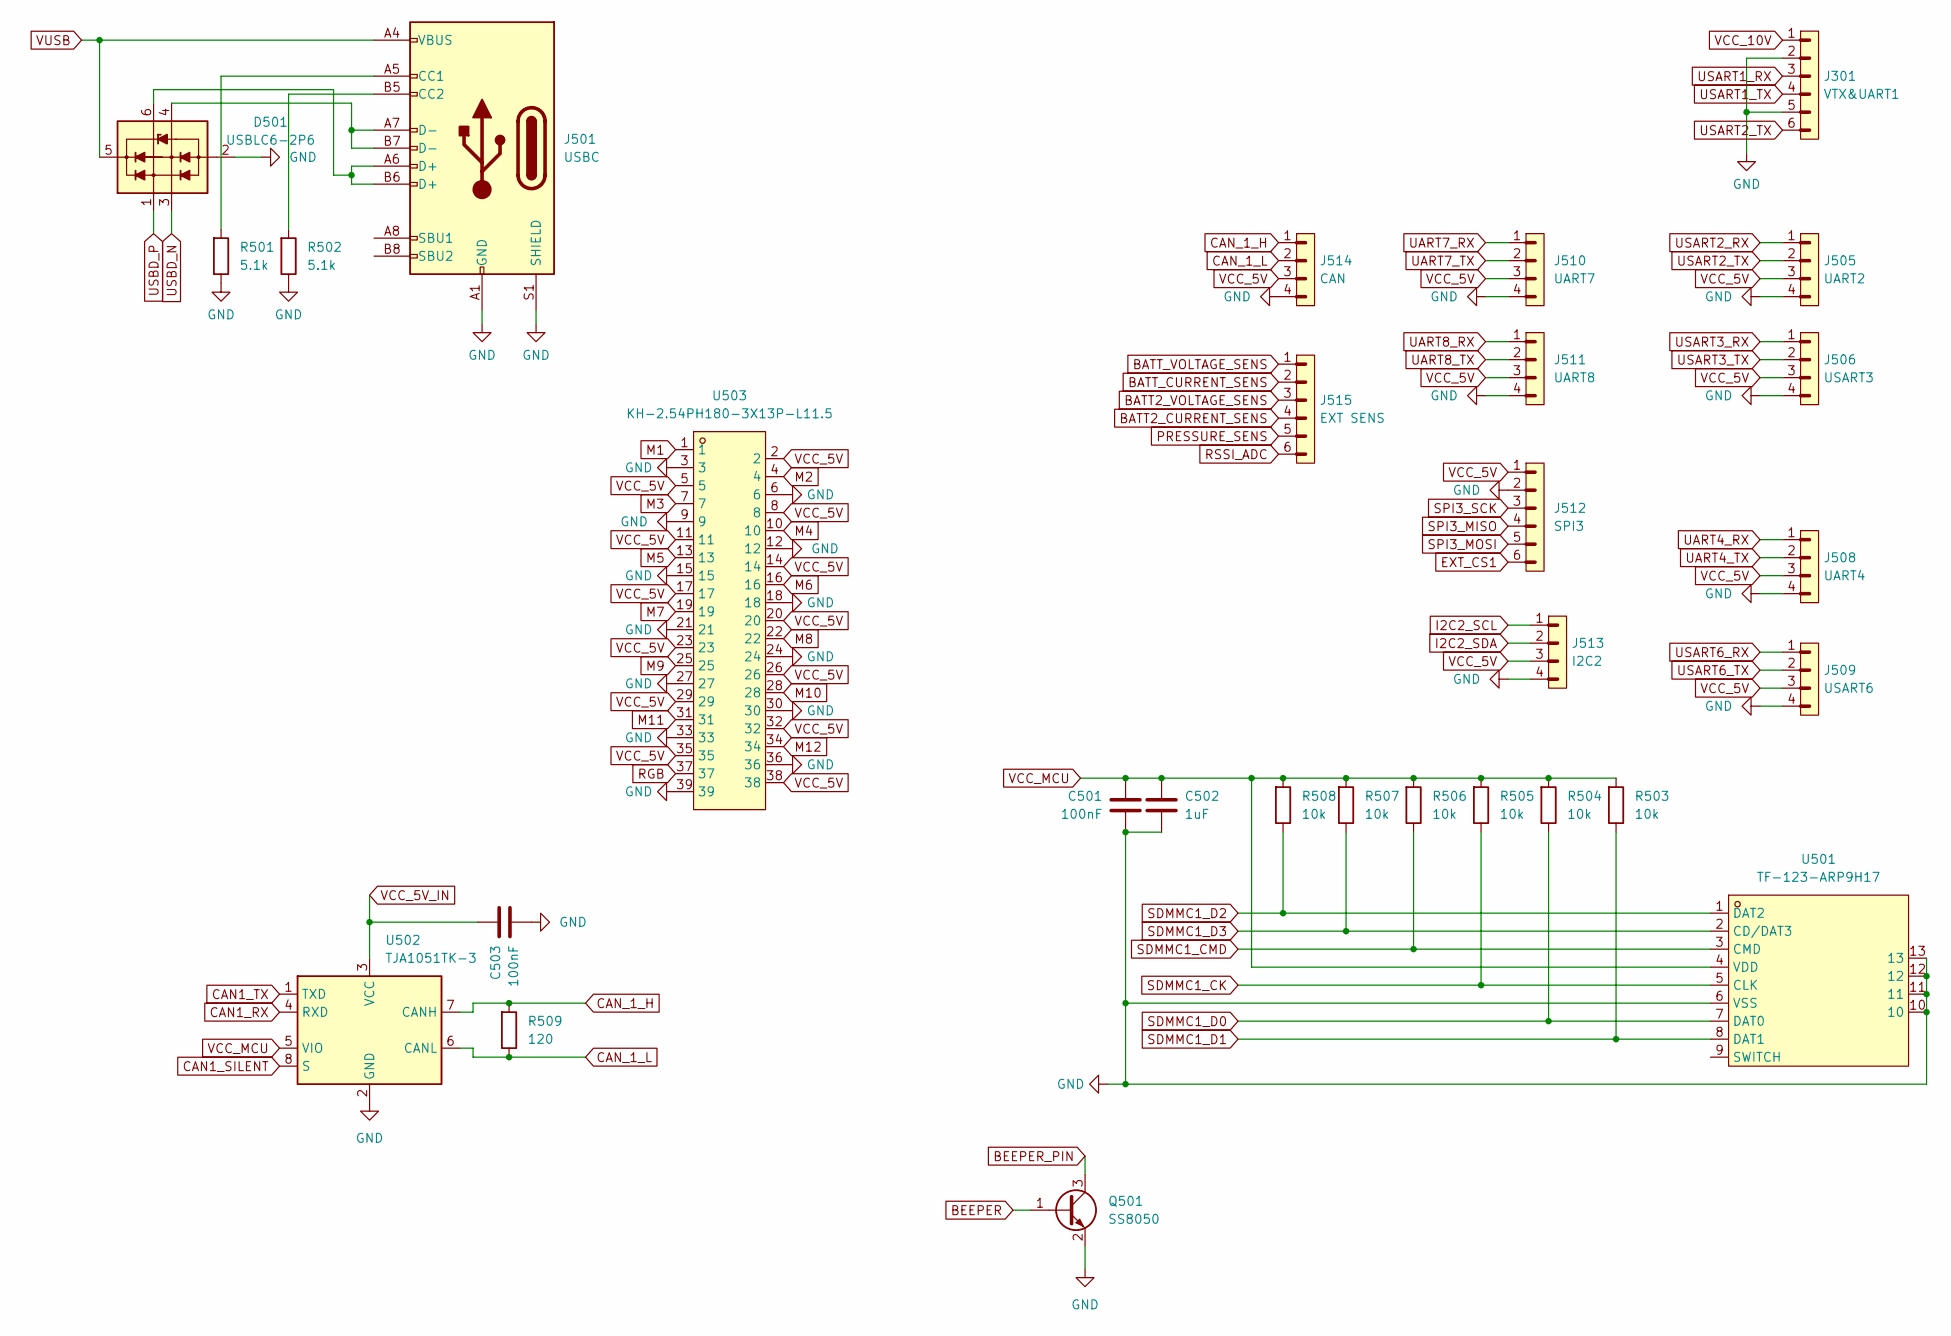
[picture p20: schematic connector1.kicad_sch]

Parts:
C501, C503: 100nF; C_0402_1005Metric
C502: 1uF; C_0402_1005Metric
D501: USBLC6-2P6; SOT-666
J301: VTX&UART1; PinHeader_1x06_P2.54mm_Vertical
J501: USBC; USB_C_Receptacle_GCT_USB4105-xx-A_16P_TopMnt_Horizontal
J505: UART2; PinHeader_1x04_P2.54mm_Vertical
J506: USART3; PinHeader_1x04_P2.54mm_Vertical
J508: UART4; PinHeader_1x04_P2.54mm_Vertical
J509: USART6; PinHeader_1x04_P2.54mm_Vertical
J510: UART7; PinHeader_1x04_P2.54mm_Vertical
J511: UART8; PinHeader_1x04_P2.54mm_Vertical
J512: SPI3; PinHeader_1x06_P2.54mm_Vertical
J513: I2C2; PinHeader_1x04_P2.54mm_Vertical
J514: CAN; PinHeader_1x04_P2.54mm_Vertical
J515: EXT SENS; PinHeader_1x06_P2.54mm_Vertical
Q501: SS8050; SOT-23
R501, R502: 5.1k; R_0402_1005Metric
R503, R504, R505, R506, R507, R508: 10k; R_0402_1005Metric
R509: 120; R_0402_1005Metric
U501: TF-123-ARP9H17; TF-SMD_TF-123-ARP9H15; LCSC Part C2982548
U502: TJA1051TK-3; HVSON-8-1EP_3x3mm_P0.65mm_EP1.6x2.4mm
U503: KH-2.54PH180-3X13P-L11.5; HDR-TH_39P-P2.54-V-M-R3-C13-S2.54; MPN KH-2.54PH180-3X13P-L11.5; LCSC Part C20610260

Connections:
BATT2_CURRENT_SENS: J515.4; also elsewhere on the board
BATT2_VOLTAGE_SENS: J515.3; also elsewhere on the board
BATT_CURRENT_SENS: J515.2; also elsewhere on the board
BATT_VOLTAGE_SENS: J515.1; also elsewhere on the board
BEEPER: Q501.1 (B); also elsewhere on the board
BEEPER_PIN: Q501.3 (C)
CAN1_RX: U502.4 (RXD); also elsewhere on the board
CAN1_SILENT: U502.8 (S); also elsewhere on the board
CAN1_TX: U502.1 (TXD); also elsewhere on the board
CAN_1_H: J514.1, R509.1, U502.7 (CANH)
CAN_1_L: J514.2, R509.2, U502.6 (CANL)
EXT_CS1: J512.6; also elsewhere on the board
GND: C501.2, C502.2, C503.2, D501.2 (VN), J301.2, J301.5, J501.A1 (GND), J501.A12 (GND), J501.B1 (GND), J501.B12 (GND), J501.S1 (SHIELD), J505.4, J506.4, J508.4, J509.4, J510.4, J511.4, J512.2, J513.4, J514.4, Q501.2 (E), R501.2, R502.2, U501.6 (VSS), U501.10, U501.11, U501.12, U501.13, U502.2 (GND), U502.9 (GND), U503.3, U503.6, U503.9, U503.12, U503.15, U503.18, U503.21, U503.24, U503.27, U503.30, U503.33, U503.36, U503.39; also elsewhere on the board
I2C2_SCL: J513.1; also elsewhere on the board
I2C2_SDA: J513.2; also elsewhere on the board
M1: U503.1; also elsewhere on the board
M2: U503.4; also elsewhere on the board
M3: U503.7; also elsewhere on the board
M4: U503.10; also elsewhere on the board
M5: U503.13; also elsewhere on the board
M6: U503.16; also elsewhere on the board
M7: U503.19; also elsewhere on the board
M8: U503.22; also elsewhere on the board
M9: U503.25; also elsewhere on the board
M10: U503.28; also elsewhere on the board
M11: U503.31; also elsewhere on the board
M12: U503.34; also elsewhere on the board
unnamed: D501.6 (L1), J501.A6 (D+), J501.B6 (D+)
unnamed: D501.4 (L2), J501.A7 (D-), J501.B7 (D-)
unnamed: J501.A5 (CC1), R501.1
unnamed: J501.B5 (CC2), R502.1
PRESSURE_SENS: J515.5; also elsewhere on the board
RGB: U503.37; also elsewhere on the board
RSSI_ADC: J515.6; also elsewhere on the board
SDMMC1_CK: R505.2, U501.5 (CLK); also elsewhere on the board
SDMMC1_CMD: R506.2, U501.3 (CMD); also elsewhere on the board
SDMMC1_D0: R504.2, U501.7 (DAT0); also elsewhere on the board
SDMMC1_D1: R503.2, U501.8 (DAT1); also elsewhere on the board
SDMMC1_D2: R508.2, U501.1 (DAT2); also elsewhere on the board
SDMMC1_D3: R507.2, U501.2 (CD/DAT3); also elsewhere on the board
SPI3_MISO: J512.4; also elsewhere on the board
SPI3_MOSI: J512.5; also elsewhere on the board
SPI3_SCK: J512.3; also elsewhere on the board
UART4_RX: J508.1; also elsewhere on the board
UART4_TX: J508.2; also elsewhere on the board
UART7_RX: J510.1; also elsewhere on the board
UART7_TX: J510.2; also elsewhere on the board
UART8_RX: J511.1; also elsewhere on the board
UART8_TX: J511.2; also elsewhere on the board
USART1_RX: J301.3; also elsewhere on the board
USART1_TX: J301.4; also elsewhere on the board
USART2_RX: J505.1; also elsewhere on the board
USART2_TX: J301.6, J505.2; also elsewhere on the board
USART3_RX: J506.1; also elsewhere on the board
USART3_TX: J506.2; also elsewhere on the board
USART6_RX: J509.1; also elsewhere on the board
USART6_TX: J509.2; also elsewhere on the board
USBD_N: D501.3 (L2); also elsewhere on the board
USBD_P: D501.1 (L1); also elsewhere on the board
VCC_5V: J505.3, J506.3, J508.3, J509.3, J510.3, J511.3, J512.1, J513.3, J514.3, U503.2, U503.5, U503.8, U503.11, U503.14, U503.17, U503.20, U503.23, U503.26, U503.29, U503.32, U503.35, U503.38; also elsewhere on the board
VCC_5V_IN: C503.1, U502.3 (VCC); also elsewhere on the board
VCC_10V: J301.1
VCC_MCU: C501.1, C502.1, R503.1, R504.1, R505.1, R506.1, R507.1, R508.1, U501.4 (VDD), U502.5 (VIO); also elsewhere on the board
VUSB: D501.5 (VP), J501.A4 (VBUS), J501.A9 (VBUS), J501.B4 (VBUS), J501.B9 (VBUS); also elsewhere on the board

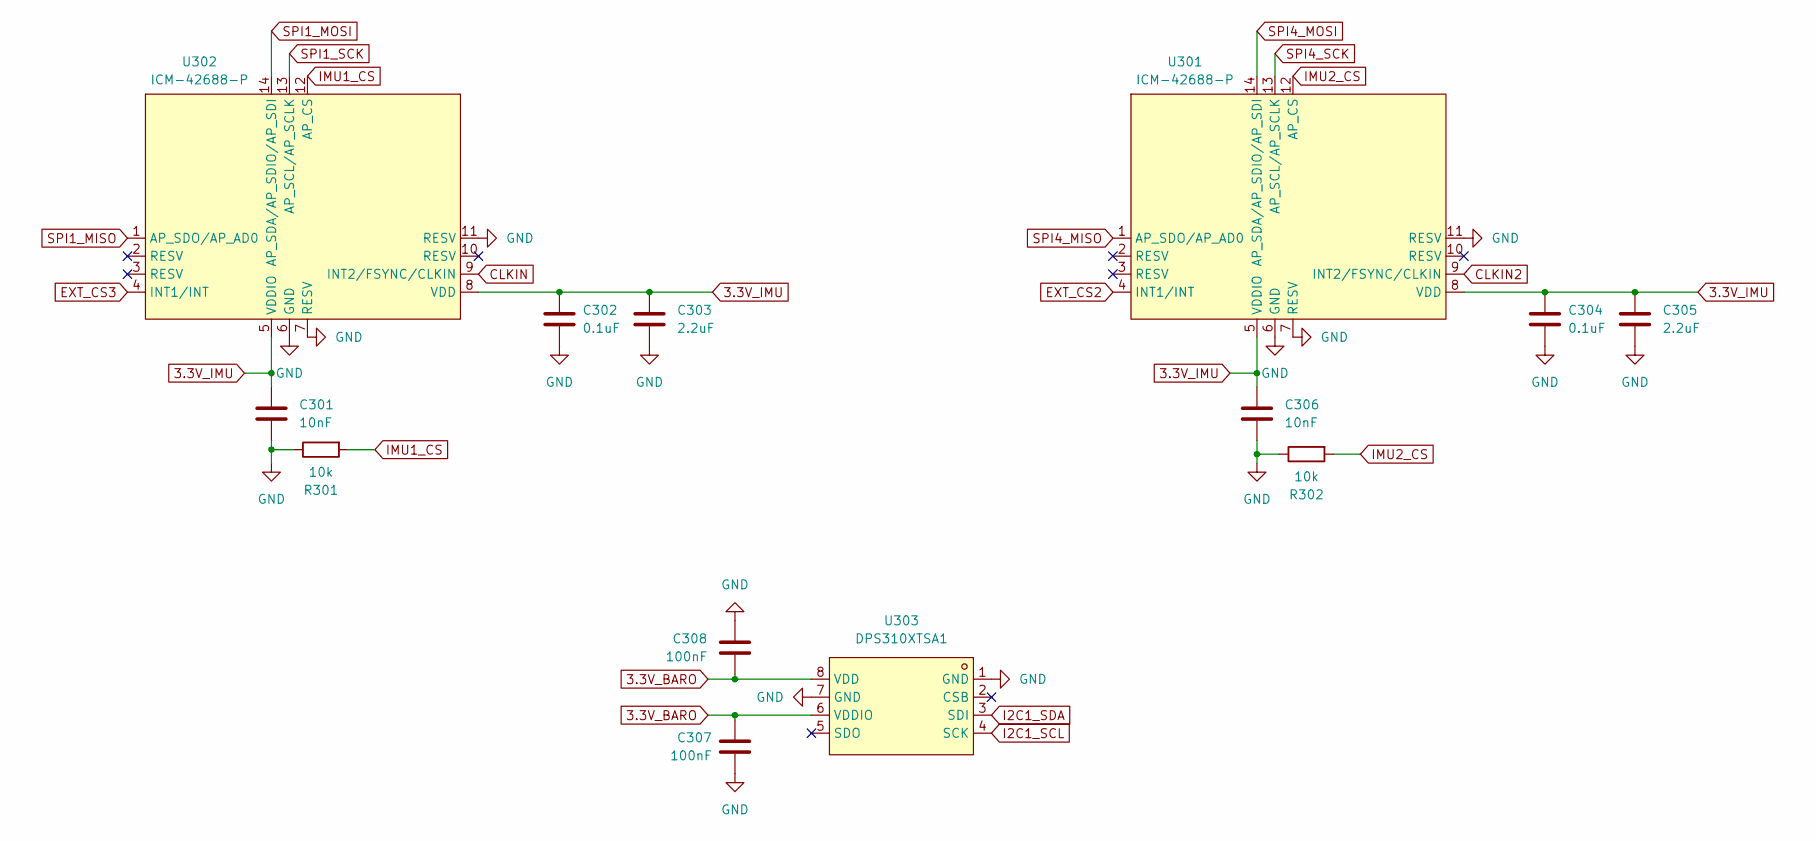
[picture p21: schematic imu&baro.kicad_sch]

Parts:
C301, C306: 10nF; C_0402_1005Metric
C302, C304: 0.1uF; C_0402_1005Metric
C303, C305: 2.2uF; C_0402_1005Metric
C307, C308: 100nF; C_0402_1005Metric
R301, R302: 10k; R_0402_1005Metric
U301, U302: ICM-42688-P; LGA-14_L3.0-W2.5-P0.50-TL; LCSC Part C1850418
U303: DPS310XTSA1; LGA-8_DPS310XTSA1; LCSC Part C130156

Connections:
3.3V_BARO: C307.1, C308.1, U303.6 (VDDIO), U303.8 (VDD); also elsewhere on the board
3.3V_IMU: C301.1, C302.1, C303.1, C304.1, C305.1, C306.1, U301.5 (VDDIO), U301.8 (VDD), U302.5 (VDDIO), U302.8 (VDD); also elsewhere on the board
CLKIN: U302.9 (INT2/FSYNC/CLKIN)
CLKIN2: U301.9 (INT2/FSYNC/CLKIN)
EXT_CS2: U301.4 (INT1/INT); also elsewhere on the board
EXT_CS3: U302.4 (INT1/INT); also elsewhere on the board
GND: C301.2, C302.2, C303.2, C304.2, C305.2, C306.2, C307.2, C308.2, R301.2, R302.2, U301.6 (GND), U301.7 (RESV), U301.11 (RESV), U302.6 (GND), U302.7 (RESV), U302.11 (RESV), U303.1 (GND), U303.7 (GND); also elsewhere on the board
I2C1_SCL: U303.4 (SCK); also elsewhere on the board
I2C1_SDA: U303.3 (SDI); also elsewhere on the board
IMU1_CS: R301.1, U302.12 (AP_CS); also elsewhere on the board
IMU2_CS: R302.1, U301.12 (AP_CS); also elsewhere on the board
SPI1_MISO: U302.1 (AP_SDO/AP_AD0); also elsewhere on the board
SPI1_MOSI: U302.14 (AP_SDA/AP_SDIO/AP_SDI); also elsewhere on the board
SPI1_SCK: U302.13 (AP_SCL/AP_SCLK); also elsewhere on the board
SPI4_MISO: U301.1 (AP_SDO/AP_AD0); also elsewhere on the board
SPI4_MOSI: U301.14 (AP_SDA/AP_SDIO/AP_SDI); also elsewhere on the board
SPI4_SCK: U301.13 (AP_SCL/AP_SCLK); also elsewhere on the board

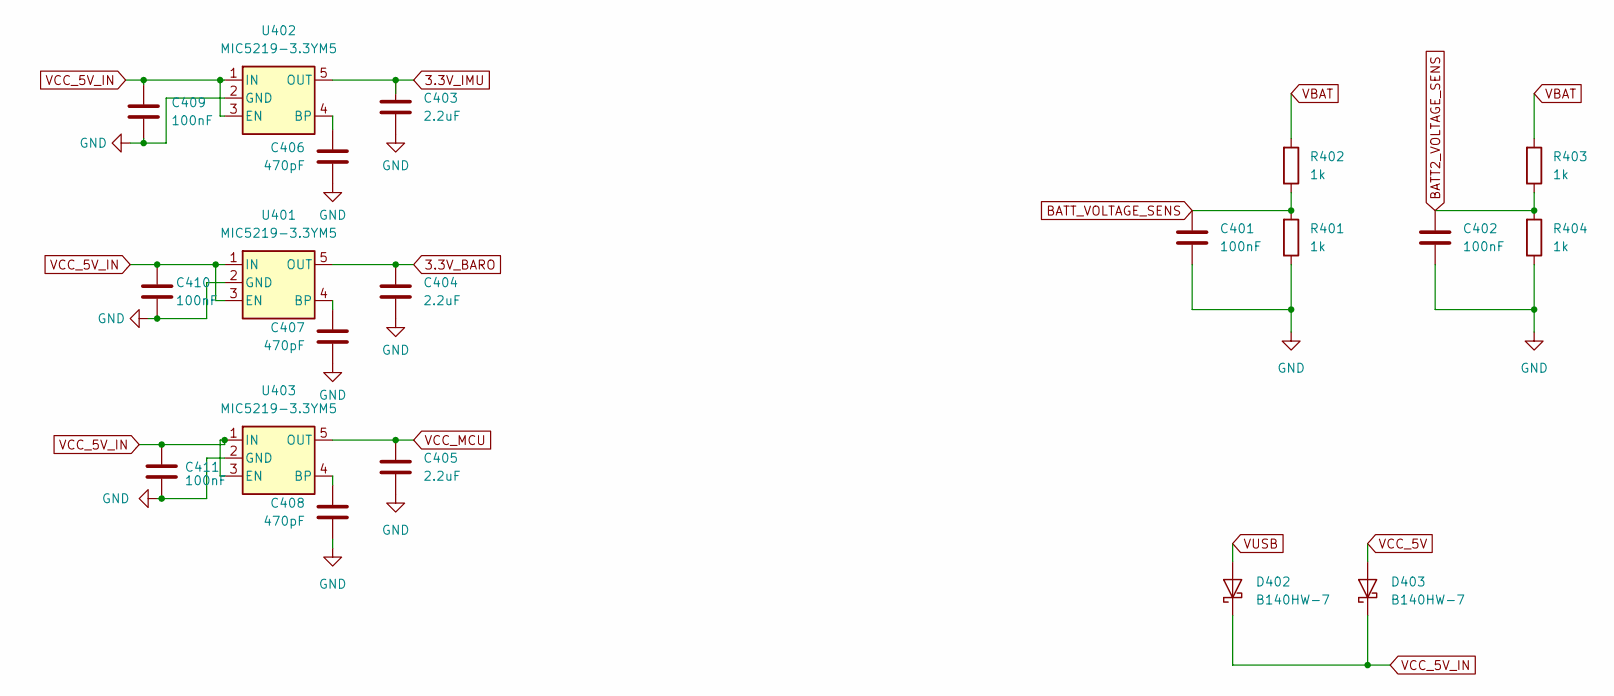
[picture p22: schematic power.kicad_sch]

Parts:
C401, C402: 100nF; C_0402_1005Metric
C403, C404, C405: 2.2uF; C_0603_1608Metric
C406, C407, C408: 470pF; C_0603_1608Metric
C409, C410, C411: 100nF; C_0603_1608Metric
D402, D403: B140HW-7; D_SOD-123; Part Number B140HW-7; JLCPCB ID C134429
R401, R402, R403, R404: 1k; R_0402_1005Metric
U401, U402, U403: MIC5219-3.3YM5; SOT-23-5

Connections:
3.3V_BARO: C404.1, U401.5 (OUT); also elsewhere on the board
3.3V_IMU: C403.1, U402.5 (OUT); also elsewhere on the board
BATT2_VOLTAGE_SENS: C402.2, R403.2, R404.1; also elsewhere on the board
BATT_VOLTAGE_SENS: C401.2, R401.1, R402.2; also elsewhere on the board
GND: C401.1, C402.1, C403.2, C404.2, C405.2, C406.2, C407.2, C408.2, C409.1, C410.1, C411.1, R401.2, R404.2, U401.2 (GND), U402.2 (GND), U403.2 (GND); also elsewhere on the board
unnamed: C407.1, U401.4 (BP)
unnamed: C406.1, U402.4 (BP)
unnamed: C408.1, U403.4 (BP)
VBAT: R402.1, R403.1
VCC_5V: D403.2 (A); also elsewhere on the board
VCC_5V_IN: C409.2, C410.2, C411.2, D402.1 (K), D403.1 (K), U401.1 (IN), U401.3 (EN), U402.1 (IN), U402.3 (EN), U403.1 (IN), U403.3 (EN); also elsewhere on the board
VCC_MCU: C405.1, U403.5 (OUT); also elsewhere on the board
VUSB: D402.2 (A); also elsewhere on the board

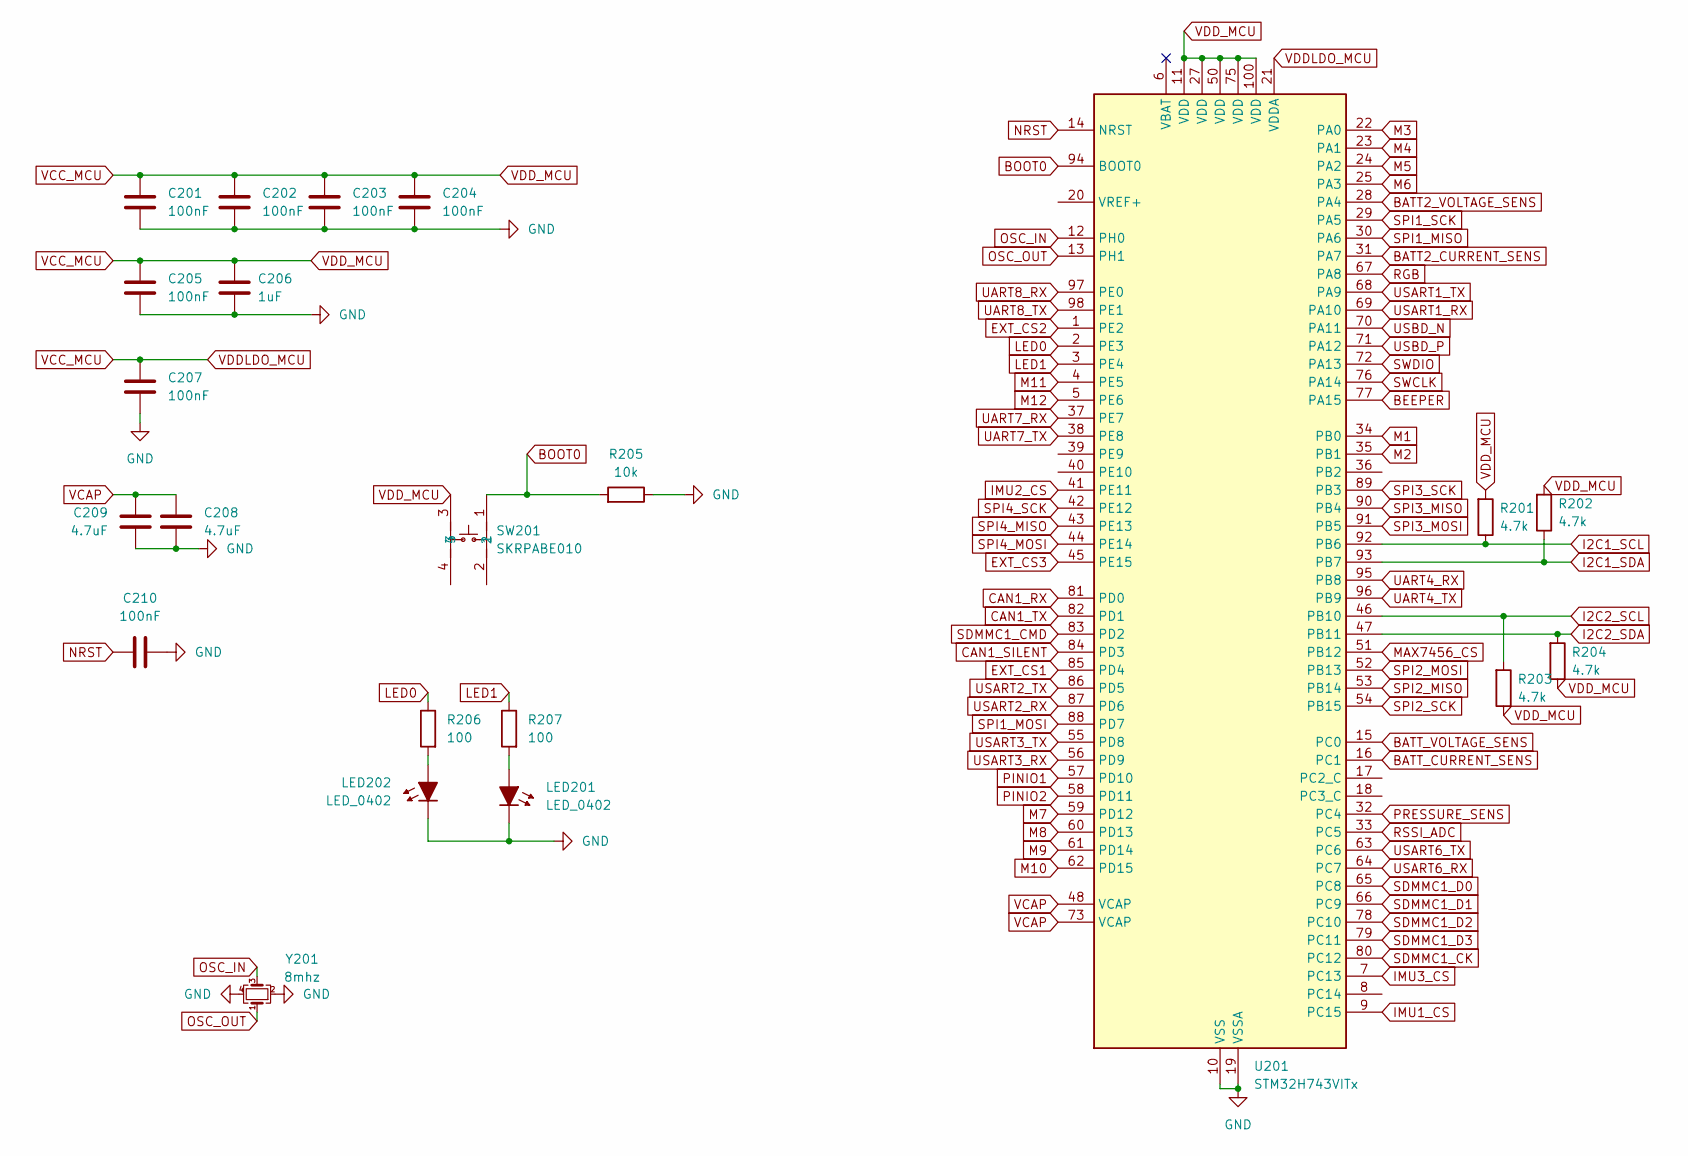
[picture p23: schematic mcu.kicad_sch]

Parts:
C201, C202, C203, C204, C205, C207, C210: 100nF; C_0402_1005Metric
C206: 1uF; C_0402_1005Metric
C208, C209: 4.7uF; C_0402_1005Metric
LED201, LED202: LED_0402; LED_0402_1005Metric
R201, R202, R203, R204: 4.7k; R_0402_1005Metric
R205: 10k; R_0402_1005Metric
R206, R207: 100; R_0402_1005Metric
SW201: SKRPABE010; KEY-SMD_4P-L4.2-W3.2-P2.20-LS4.6; LCSC Part C115360
U201: STM32H743VITx; LQFP-100_14x14mm_P0.5mm
Y201: 8mhz; Crystal_SMD_2520-4Pin_2.5x2.0mm

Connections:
BATT2_CURRENT_SENS: U201.31 (PA7); also elsewhere on the board
BATT2_VOLTAGE_SENS: U201.28 (PA4); also elsewhere on the board
BATT_CURRENT_SENS: U201.16 (PC1); also elsewhere on the board
BATT_VOLTAGE_SENS: U201.15 (PC0); also elsewhere on the board
BEEPER: U201.77 (PA15); also elsewhere on the board
BOOT0: R205.1, SW201.1, U201.94 (BOOT0)
CAN1_RX: U201.81 (PD0); also elsewhere on the board
CAN1_SILENT: U201.84 (PD3); also elsewhere on the board
CAN1_TX: U201.82 (PD1); also elsewhere on the board
EXT_CS1: U201.85 (PD4); also elsewhere on the board
EXT_CS2: U201.1 (PE2); also elsewhere on the board
EXT_CS3: U201.45 (PE15); also elsewhere on the board
GND: C201.2, C202.2, C203.2, C204.2, C205.2, C206.2, C207.2, C208.2, C209.2, C210.2, LED201.1 (K), LED202.1 (K), R205.2, U201.10 (VSS), U201.19 (VSSA), U201.26 (VSS), U201.49 (VSS), U201.74 (VSS), U201.99 (VSS), Y201.2, Y201.4; also elsewhere on the board
I2C1_SCL: R201.2, U201.92 (PB6); also elsewhere on the board
I2C1_SDA: R202.2, U201.93 (PB7); also elsewhere on the board
I2C2_SCL: R203.1, U201.46 (PB10); also elsewhere on the board
I2C2_SDA: R204.1, U201.47 (PB11); also elsewhere on the board
IMU1_CS: U201.9 (PC15); also elsewhere on the board
IMU2_CS: U201.41 (PE11); also elsewhere on the board
IMU3_CS: U201.7 (PC13)
LED0: R206.2, U201.2 (PE3)
LED1: R207.2, U201.3 (PE4)
M1: U201.34 (PB0); also elsewhere on the board
M2: U201.35 (PB1); also elsewhere on the board
M3: U201.22 (PA0); also elsewhere on the board
M4: U201.23 (PA1); also elsewhere on the board
M5: U201.24 (PA2); also elsewhere on the board
M6: U201.25 (PA3); also elsewhere on the board
M7: U201.59 (PD12); also elsewhere on the board
M8: U201.60 (PD13); also elsewhere on the board
M9: U201.61 (PD14); also elsewhere on the board
M10: U201.62 (PD15); also elsewhere on the board
M11: U201.4 (PE5); also elsewhere on the board
M12: U201.5 (PE6); also elsewhere on the board
MAX7456_CS: U201.51 (PB12)
NRST: C210.1, U201.14 (NRST)
unnamed: LED201.2 (A), R207.1
unnamed: LED202.2 (A), R206.1
OSC_IN: U201.12 (PH0), Y201.3
OSC_OUT: U201.13 (PH1), Y201.1
PINIO1: U201.57 (PD10)
PINIO2: U201.58 (PD11)
PRESSURE_SENS: U201.32 (PC4); also elsewhere on the board
RGB: U201.67 (PA8); also elsewhere on the board
RSSI_ADC: U201.33 (PC5); also elsewhere on the board
SDMMC1_CK: U201.80 (PC12); also elsewhere on the board
SDMMC1_CMD: U201.83 (PD2); also elsewhere on the board
SDMMC1_D0: U201.65 (PC8); also elsewhere on the board
SDMMC1_D1: U201.66 (PC9); also elsewhere on the board
SDMMC1_D2: U201.78 (PC10); also elsewhere on the board
SDMMC1_D3: U201.79 (PC11); also elsewhere on the board
SPI1_MISO: U201.30 (PA6); also elsewhere on the board
SPI1_MOSI: U201.88 (PD7); also elsewhere on the board
SPI1_SCK: U201.29 (PA5); also elsewhere on the board
SPI2_MISO: U201.53 (PB14)
SPI2_MOSI: U201.52 (PB13)
SPI2_SCK: U201.54 (PB15)
SPI3_MISO: U201.90 (PB4); also elsewhere on the board
SPI3_MOSI: U201.91 (PB5); also elsewhere on the board
SPI3_SCK: U201.89 (PB3); also elsewhere on the board
SPI4_MISO: U201.43 (PE13); also elsewhere on the board
SPI4_MOSI: U201.44 (PE14); also elsewhere on the board
SPI4_SCK: U201.42 (PE12); also elsewhere on the board
SWCLK: U201.76 (PA14)
SWDIO: U201.72 (PA13)
UART4_RX: U201.95 (PB8); also elsewhere on the board
UART4_TX: U201.96 (PB9); also elsewhere on the board
UART7_RX: U201.37 (PE7); also elsewhere on the board
UART7_TX: U201.38 (PE8); also elsewhere on the board
UART8_RX: U201.97 (PE0); also elsewhere on the board
UART8_TX: U201.98 (PE1); also elsewhere on the board
USART1_RX: U201.69 (PA10); also elsewhere on the board
USART1_TX: U201.68 (PA9); also elsewhere on the board
USART2_RX: U201.87 (PD6); also elsewhere on the board
USART2_TX: U201.86 (PD5); also elsewhere on the board
USART3_RX: U201.56 (PD9); also elsewhere on the board
USART3_TX: U201.55 (PD8); also elsewhere on the board
USART6_RX: U201.64 (PC7); also elsewhere on the board
USART6_TX: U201.63 (PC6); also elsewhere on the board
USBD_N: U201.70 (PA11); also elsewhere on the board
USBD_P: U201.71 (PA12); also elsewhere on the board
VCAP: C208.1, C209.1, U201.48 (VCAP), U201.73 (VCAP)
VCC_MCU: C201.1, C202.1, C203.1, C204.1, C205.1, C206.1, C207.1, R201.1, R202.1, R203.2, R204.2, SW201.3, U201.11 (VDD), U201.21 (VDDA), U201.27 (VDD), U201.50 (VDD), U201.75 (VDD), U201.100 (VDD); also elsewhere on the board

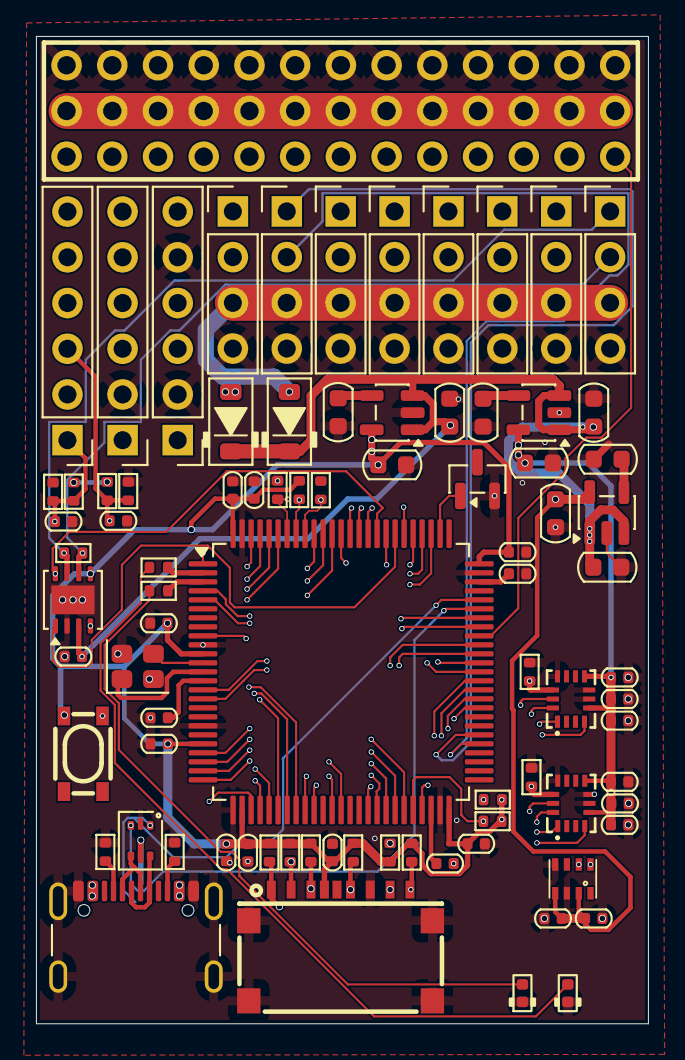
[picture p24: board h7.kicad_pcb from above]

Board: 8 copper layers, 34.0 x 54.8 mm, 84 parts (0 on the bottom side), 89 nets.

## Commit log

2026-07-01 updated pinout
    [h7.kicad_sch, mcu.kicad_sch]
2026-07-01 todays progress with schematic and pinout
    [h7.kicad_sch, imu&baro.kicad_sch, mcu.kicad_sch]
2026-07-01 todays progresss
    [imu&baro.kicad_sch, mcu.kicad_sch]
2026-07-02 before final
    [connector1.kicad_sch, h7.kicad_pcb, h7.kicad_sch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]
2026-07-02 changed the readme and kicad things
    [bom.csv, designators.csv, h7.kicad_pcb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]
